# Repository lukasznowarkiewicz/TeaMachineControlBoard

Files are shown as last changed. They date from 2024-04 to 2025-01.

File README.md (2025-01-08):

# TeaMachineControlBoard
Tea Machine

This project was developed as part of my bachelor's thesis.  The main goal of the whole project was to design a working control board for a
tea express, implement and test the system. The Kicad program was used to design it.
The PCB board is four-layered, made of FR-4 laminate. It contains components
made in both surface mount technology (SMT) and through-hole technology (THT).
After completing the design and assembling the production documentation, an order for
the board was made from the company JLCPCB. The components were assembled
using a pick and place (PnP) machine and by hand. Individual parts of the system were
started one by one until the complete device was fully operational. To this end, a piece
of software was written to sequentially control individual outputs. Electrical and
thermal tests were conducted using a thermal imaging camera.

## Schematics

The design incorporates an RP Pico in a devkit form, three I2C PCF8575 expanders, and a step-down converter from 12V to 5V based on the XL4015. An alternative solution for potential issues is the LM7805, designated as 'do not populate'. The conversion from 12V to 3.3V is achieved using an NCP1117. The project features universal input-output blocks with adjustable logic voltage, RGB strip control, and six 12V switching outputs.
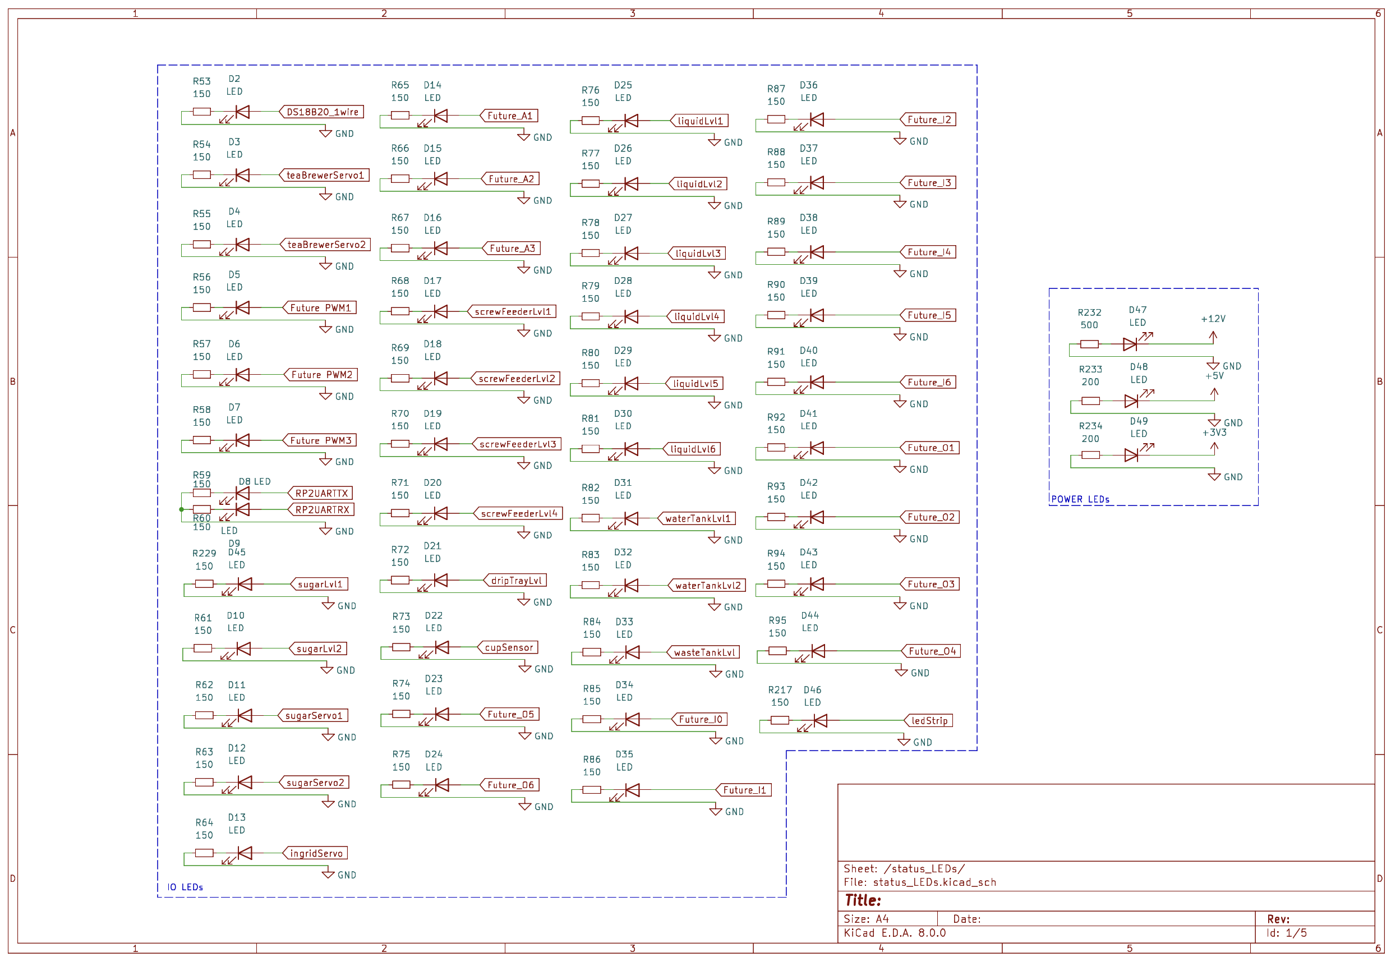
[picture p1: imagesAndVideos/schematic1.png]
Schematic view 1

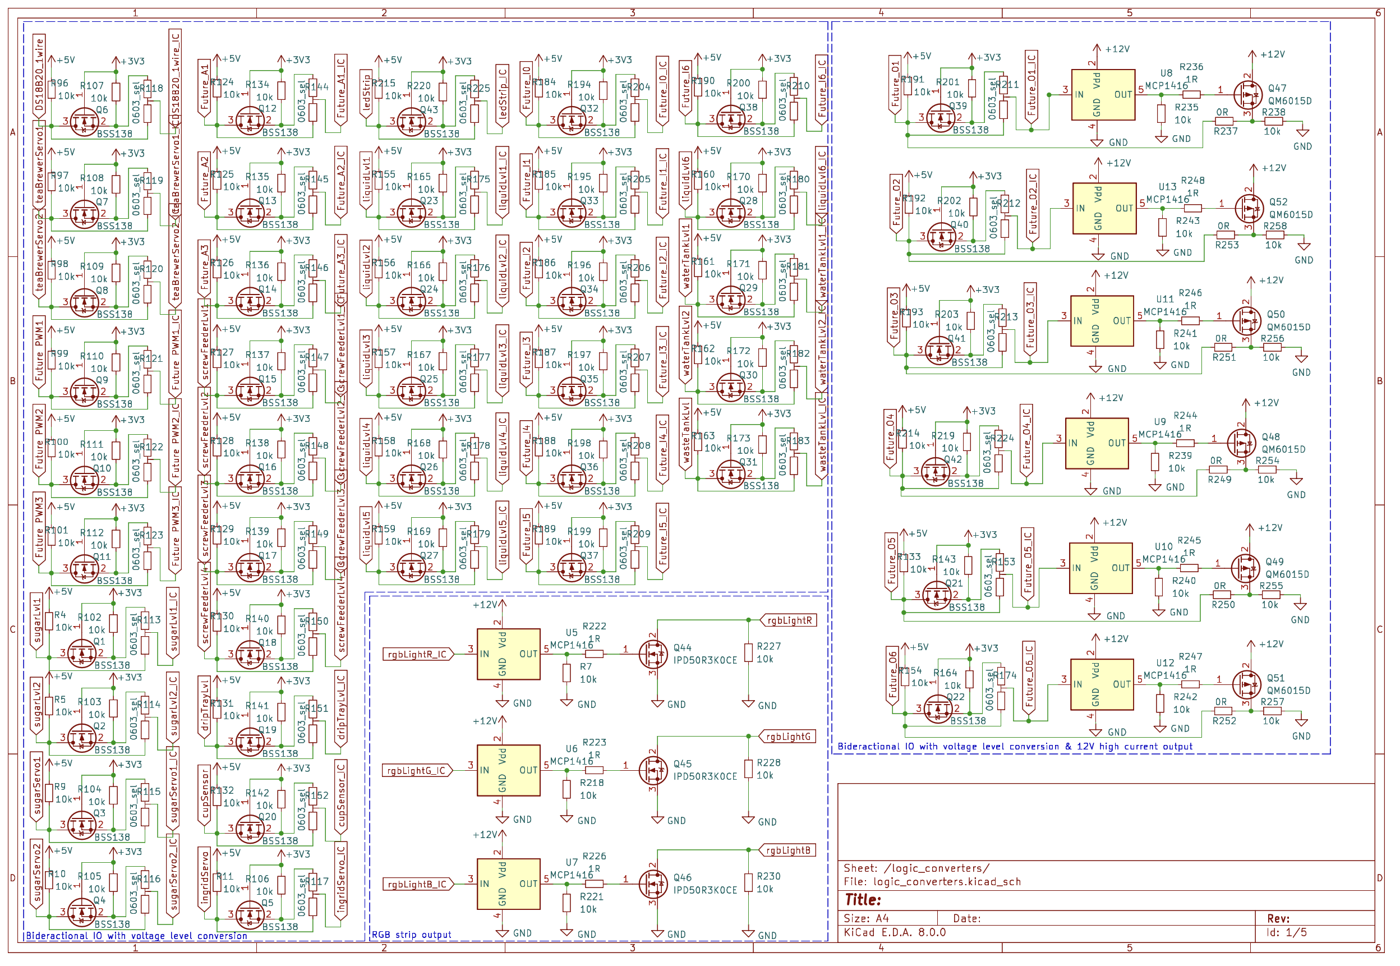
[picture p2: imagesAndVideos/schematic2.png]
Schematic view 2

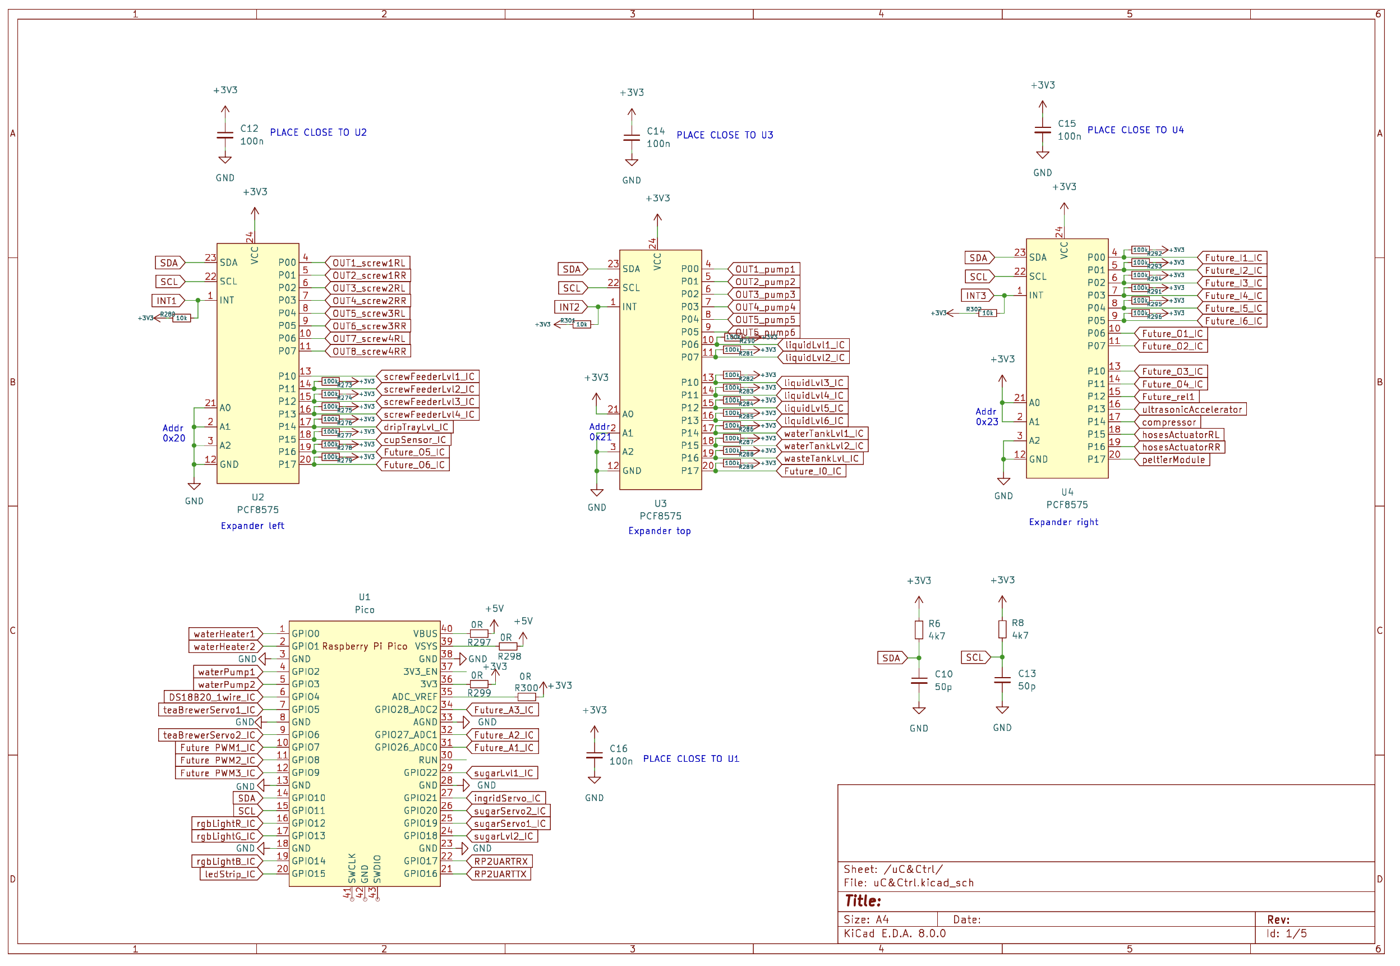
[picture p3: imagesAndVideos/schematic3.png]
Schematic view 3

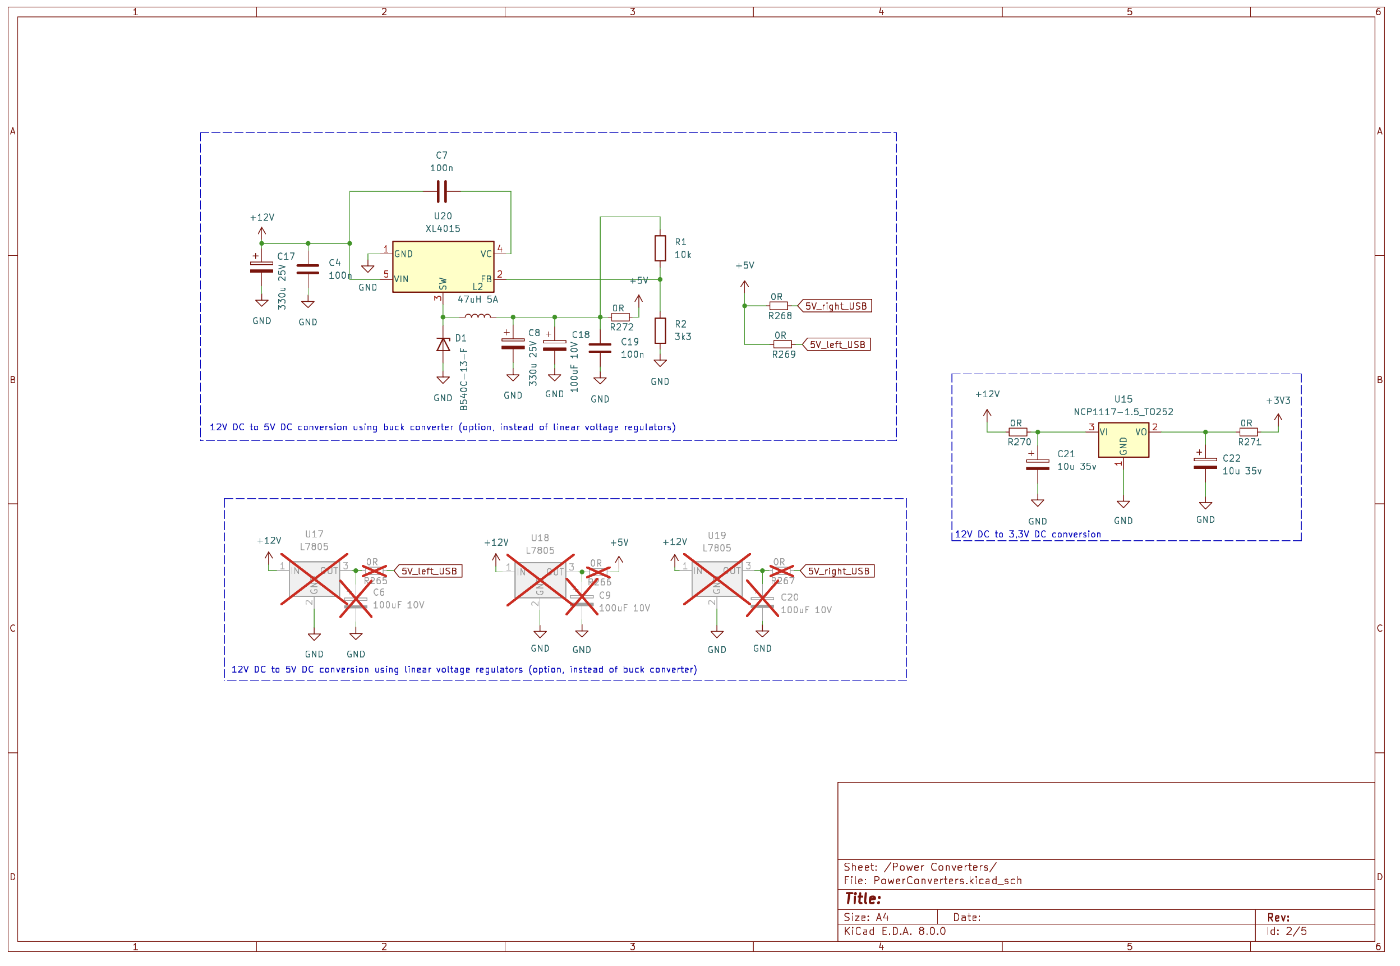
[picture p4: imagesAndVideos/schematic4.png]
Schematic view 4

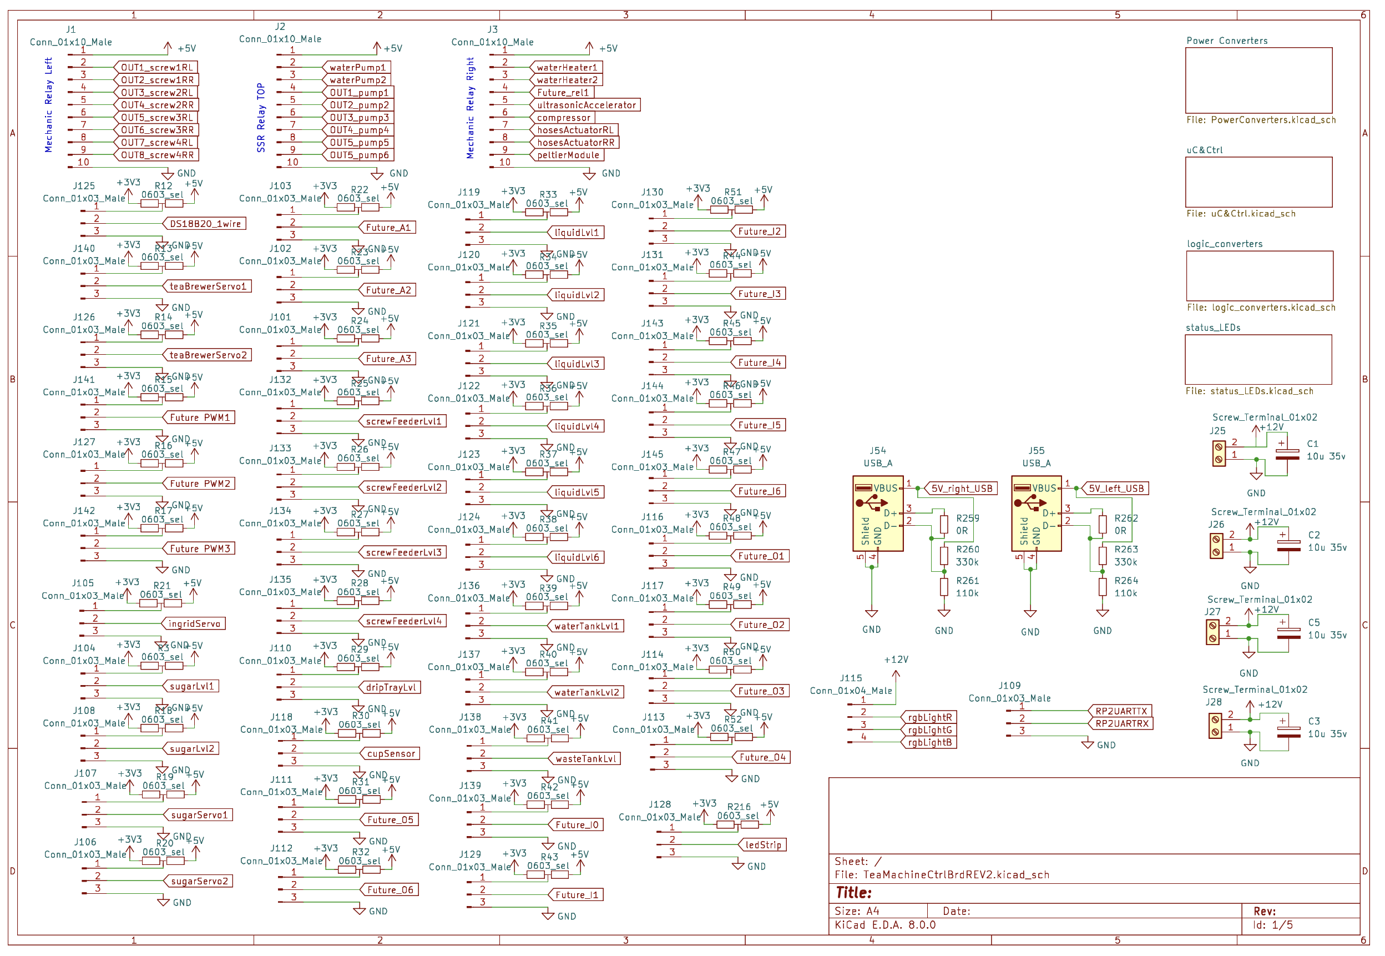
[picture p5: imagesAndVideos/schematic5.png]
Schematic view 5


## PCB Details

The PCB is a four-layer board that has been ordered and manufactured through JLCPCB.
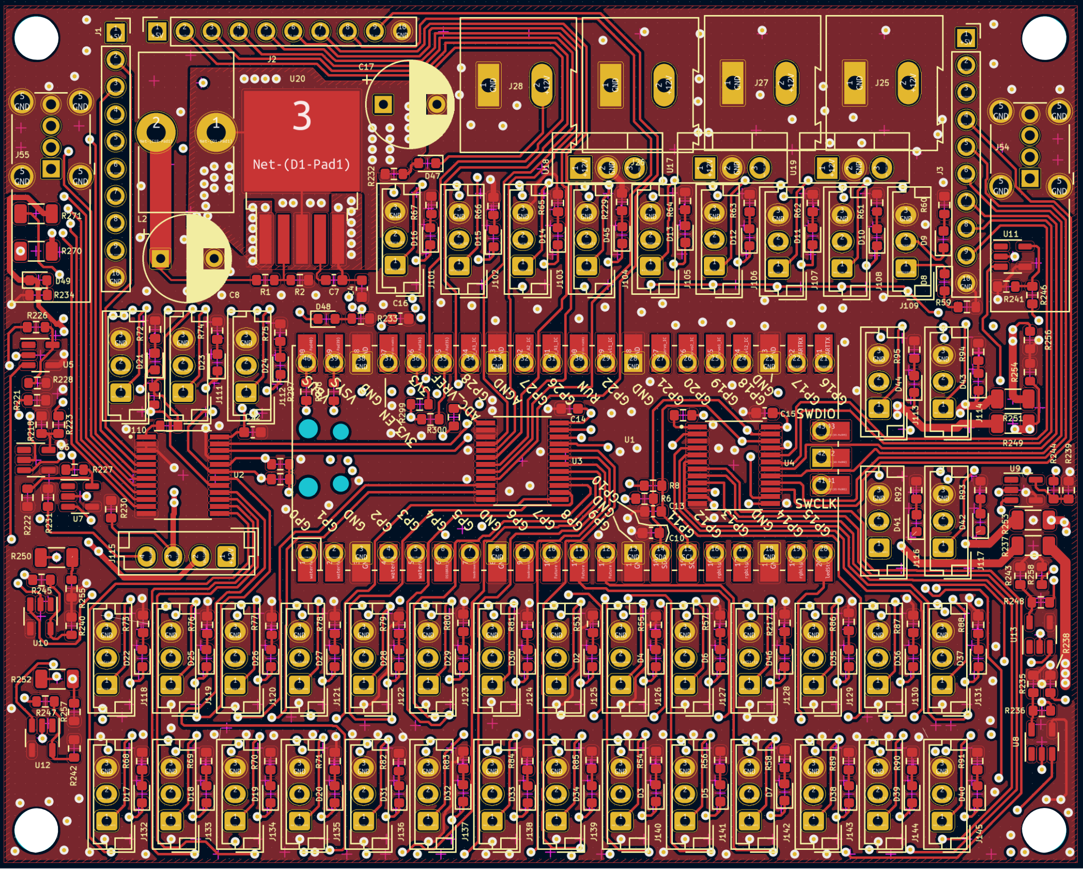
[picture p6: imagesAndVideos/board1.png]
Board view 1

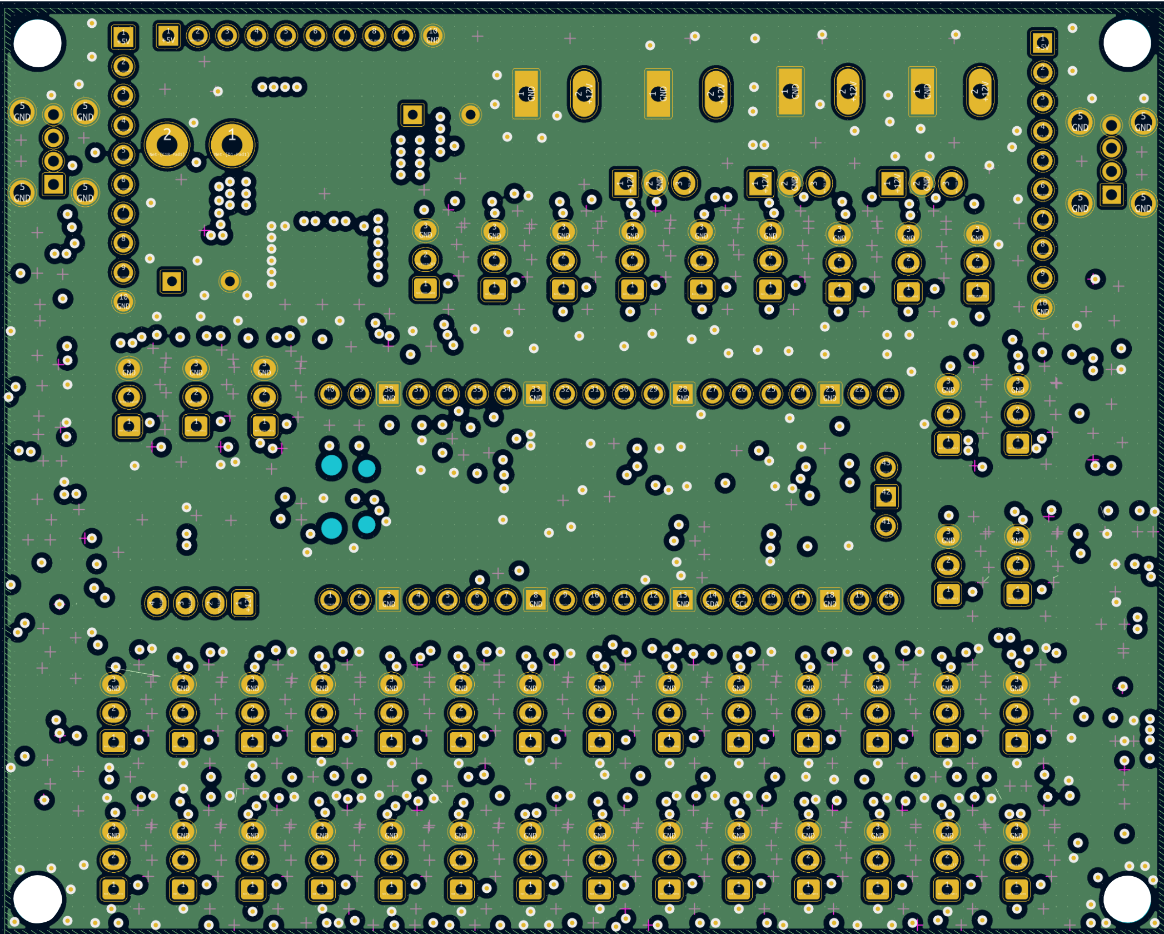
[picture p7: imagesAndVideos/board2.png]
Board view 2

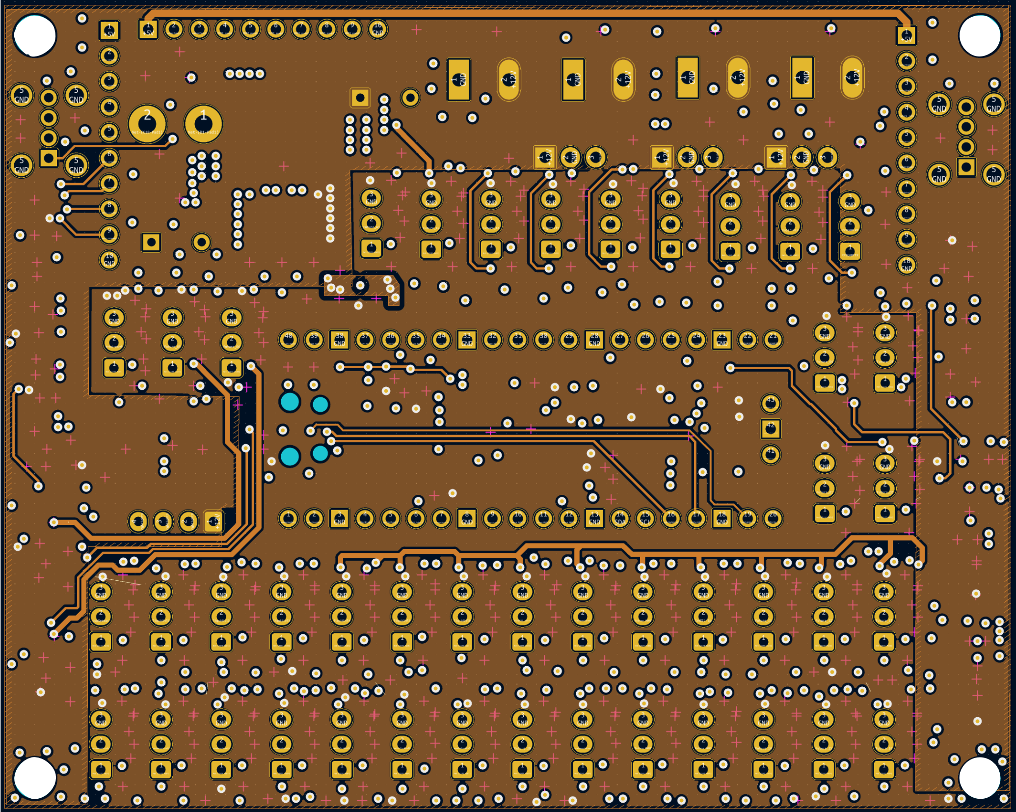
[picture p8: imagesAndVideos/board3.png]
Board view 3

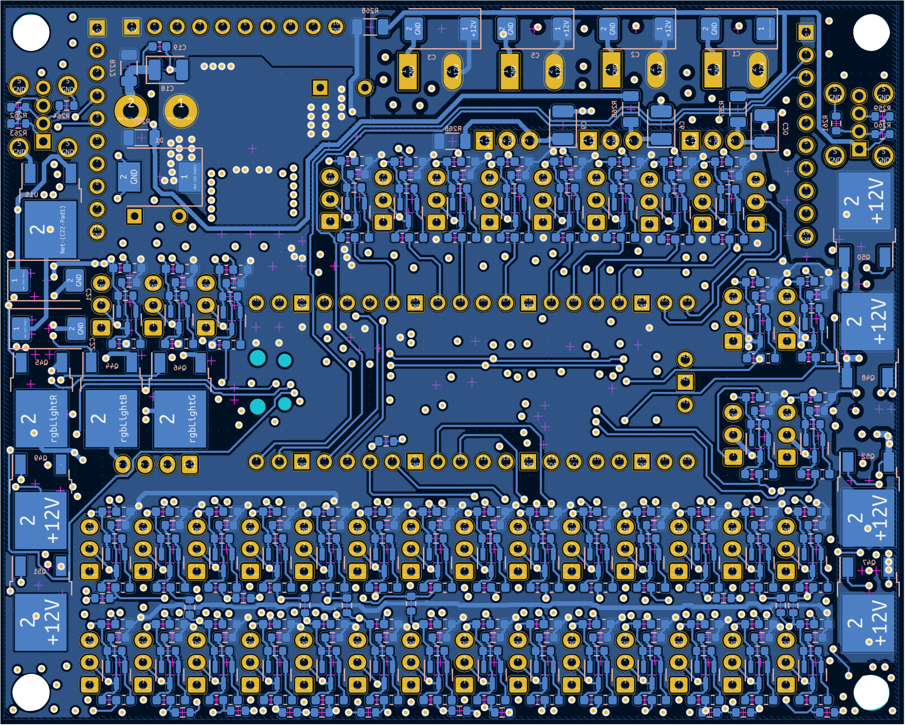
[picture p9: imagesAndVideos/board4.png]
Board view 4


## Assembly

SMD components were positioned using a pick & place machine and subsequently soldered in a reflow oven.

## Troubleshooting During System Startup

#### Initial Visual Inspection and Microscopic Examination

The process of bringing the PCB to life began with a thorough visual inspection, utilizing a microscope to check all components for possible imperfections. Identified issues included shorts between IC pins, unsoldered points, misplaced elements, and improperly seated or oriented components. These were rectified using a traditional soldering iron and a hot air rework station.

#### Electrical and Continuity Checks

Further checks were made for shorts between power signals and for the continuity of other critical signals. Intentionally, voltage converter connecting resistors were not installed initially to verify idle state voltages provided by the converters. Upon applying 12V from a lab power supply with a current limit set to 100mA, both the XL4015 converter and the NCP1117 voltage regulator were tested for their output voltages.

#### Soldering Connecting Resistors

After these initial tests, connecting resistors R272, R268, R269, and R271 were soldered to link the converter to the power lines. The power supply was re-engaged to ensure no components caused shorts or drew excessive current. No shorts were observed, but unlit LEDs indicated issues with specific output channels, attributed to improper solder joints and subsequently corrected.

#### Introduction of the Microcontroller

The lab power supply was disconnected and a pin header was soldered to mount the RPI Pico module. A temporary connection from the module's 3V3 signal to the PCB's 3.3V power supply was established via a jumper resistor (R299). The system was then connected to a computer, and test software was uploaded to configure all RPI Pico pins and outputs, sequentially illuminating LEDs to indicate functionality. I2C expanders PCF8575 were also configured as outputs, periodically set to a low state, to observe system behavior post-microcontroller installation.

#### Encountering and Addressing Complex Issues

Despite these steps, the system did not perform as expected, with some LEDs not lighting up at all or flashing out of sequence. The troubleshooting process was time-consuming and complex, involving issues partly due to design and partly external factors. One identified problem was a solder bridge between SDA and SCL pins on an expander, only visible under a microscope at a steep angle, which impeded I2C communication.

#### Investigating Internal Short Circuits

Upon a more detailed inspection, no shorts were found on the I2C bus components. Signal routing on the PCB was verified to be correct. After desoldering all ICs and connected components, SDA and SCL lines were still found to be shorted. A thorough microscopic inspection of both signal layers did not reveal any anomalies, suggesting a potential internal PCB layer short. A radical approach using a constant current supply and thermal imaging to locate the short was undertaken. The application of approximately 2V caused a current flow of 3A, which unexpectedly ceased, indicating the short was cleared by burning through the bridging element, though its exact location remained undetermined.

#### I2C Communication Challenges

Attempts to re-establish I2C communication were made using Adafruit's I2C detect software, which indicated a lack of response from devices at certain addresses. Voltage checks on SDA and SCL lines were correct, and signal analysis confirmed correct transmission of SETUP messages without acknowledgment from the addressed device. This led to the discovery of counterfeit PCF8575 chips, differentiated by their markings and the absence of Philips branding, which ceased semiconductor production in 2006.

#### Software Bugs and GPIO Misconfigurations

Software errors, including inappropriate configuration of GPIO ports for I2C communication, resulted in internal shorts and reset loops. These were traced back to both the test program and the Arduino IDE library for the RPI Pico, with unresolved issues related to GPIO pin configuration potentially causing conflicts within the I2C block.

## Tests Summary

#### Long-Term Operation and Thermal Analysis

The tests were designed to observe the board's performance over extended periods and analyze the thermal behavior of individual components and the entire system. After resolving software-related stability issues, the board was left to operate idly for more than 24 hours, during which it continued to function without any peripheral devices connected. Power cycling tests showed consistent and reliable startup.

#### Voltage Converter and Linear Regulator Tests

Initial voltage accuracy was confirmed using a multimeter and oscilloscope. Load tests were conducted using an active load and thermal imaging to examine two main components: the 12V to 5V converter and the 12V to 3.3V linear regulator.

For the XL4015 converter, a 15W load was applied. The thermal image captured showed that all components, including the coil, remained within safe operational temperatures, although the coil's temperature was unexpectedly high. It was suggested that future designs might consider an SMD-mounted coil to dissipate heat more efficiently or a coil with lower resistance. However, component modification was deemed unnecessary as the operational parameters were within acceptable limits.

The linear regulator test subjected the NCP1117 to a significant load, resulting in notable heating, typical of linear regulators due to the substantial voltage difference between input and output. It was noted that the tested load was much higher than what the device would experience during normal operation, with the RPI Pico's internal 5V to 3.3V regulator handling most power requirements, leaving the NCP1117 to power low-current sensors.

#### Final Application Testing

After SMT and THT assembly and initial board startup, the board was tested in its intended application within a tea brewing machine. This involved connecting an LED strip and all relay modules and running test software to verify correct operation, including alternating relay activation, which functioned as expected. Thermal imaging of the board in operation highlighted the main heat sources, including voltage converters, the RP2040 chip, and expanders, without detecting dangerously high temperatures that could compromise the system's safety.

#### Firmware for Testing

A test program was developed to configure all RPI Pico pins (excluding I2C communication pins) as outputs, executing various output sequences. This setup, combined with installed LEDs, allowed for verifying the operation of each output. Similarly, all signals on the PCF8575 expanders were set as outputs and temporarily pulled to ground level. The program, written in the Arduino IDE, successfully demonstrated the board's functionality through sequential activation and deactivation of outputs and LEDs, confirming the successful operation and stability of the system under test conditions.

Tea Machine Control Board Closeup
Tea Machine Photo

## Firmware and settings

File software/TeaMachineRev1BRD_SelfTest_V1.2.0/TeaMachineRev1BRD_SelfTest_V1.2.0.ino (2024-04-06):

#include "Arduino.h"
#include "Adafruit_PCF8575.h"
Adafruit_PCF8575 pcf;
void setup() {
  pinMode(LED_BUILTIN, OUTPUT);
    digitalWrite(LED_BUILTIN, HIGH); 
  for ( uint8_t i = 0; i<=28 ; i++) {
    if(i!=10 && i!=11 && i!=22){
      pinMode(i, OUTPUT);
    }
  }
  pinMode(22, INPUT);
  delay(2000);
//    while (!Serial) { delay(10); }
  Serial.begin(115200);
  Serial.println("Adafruit PCF8575 LED blink test");

  if (!pcf.begin(0x20, &Wire)) {
    Serial.println("Couldn't find PCF8575");
  }
  for (uint8_t p=0; p<16; p++) {
    pcf.pinMode(p, OUTPUT);
  }
pcf.begin(0x21, &Wire);
  for (uint8_t p=0; p<16; p++) {
    pcf.pinMode(p, OUTPUT);
  }
pcf.begin(0x23, &Wire);
  for (uint8_t p=0; p<16; p++) {
    pcf.pinMode(p, OUTPUT);
  }
  
Serial.println("Config done");
delay(100);
  
}

void loop() {
  digitalWrite(LED_BUILTIN, HIGH); 
  digitalWrite(LED_BUILTIN, HIGH);  
  Serial.println("LED_BUILTIN, HIGH");
  delay(100);
  pcf.begin(0x20, &Wire);
  for (uint8_t p=0; p<16; p++) {
    pcf.digitalWrite(p, LOW);  // turn LED on by sinking current to ground
  }
  Serial.println("PCFs low");
  delay(1000);
  for (uint8_t p=0; p<16; p++) {
    pcf.digitalWrite(p, HIGH); // turn LED off by turning off sinking transistor
  }
  Serial.println("PCFs high");
  delay(1000);

  pcf.begin(0x21, &Wire);
    for (uint8_t p=0; p<16; p++) {
    pcf.digitalWrite(p, LOW);  // turn LED on by sinking current to ground
  }
    Serial.println("PCFs low");
delay(1000);
  for (uint8_t p=0; p<16; p++) {
    pcf.digitalWrite(p, HIGH); // turn LED off by turning off sinking transistor
  }
  Serial.println("PCFs high");

  pcf.begin(0x23, &Wire);
    for (uint8_t p=0; p<16; p++) {
    pcf.digitalWrite(p, LOW);  // turn LED on by sinking current to ground
  }
    Serial.println("PCFs low");
delay(1000);
  for (uint8_t p=0; p<16; p++) {
    pcf.digitalWrite(p, HIGH); // turn LED off by turning off sinking transistor
  }
  Serial.println("PCFs high");
  
  digitalWrite(LED_BUILTIN, LOW);   
  for(uint8_t i=0; i<28 ; i++){
     if(i!=10 && i!=11 && i!=22){
      digitalWrite(i, HIGH);
    }
    delay(100);
    if(i!=10 && i!=11 && i!=22){
      digitalWrite(i, LOW);
    }
  }
}
